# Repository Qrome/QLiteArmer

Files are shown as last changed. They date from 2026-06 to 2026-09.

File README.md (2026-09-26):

# QLiteArmer — HD Armer and Full OSD with Dual‑Core RP2040 Telemetry MSP DisplayPort Processor

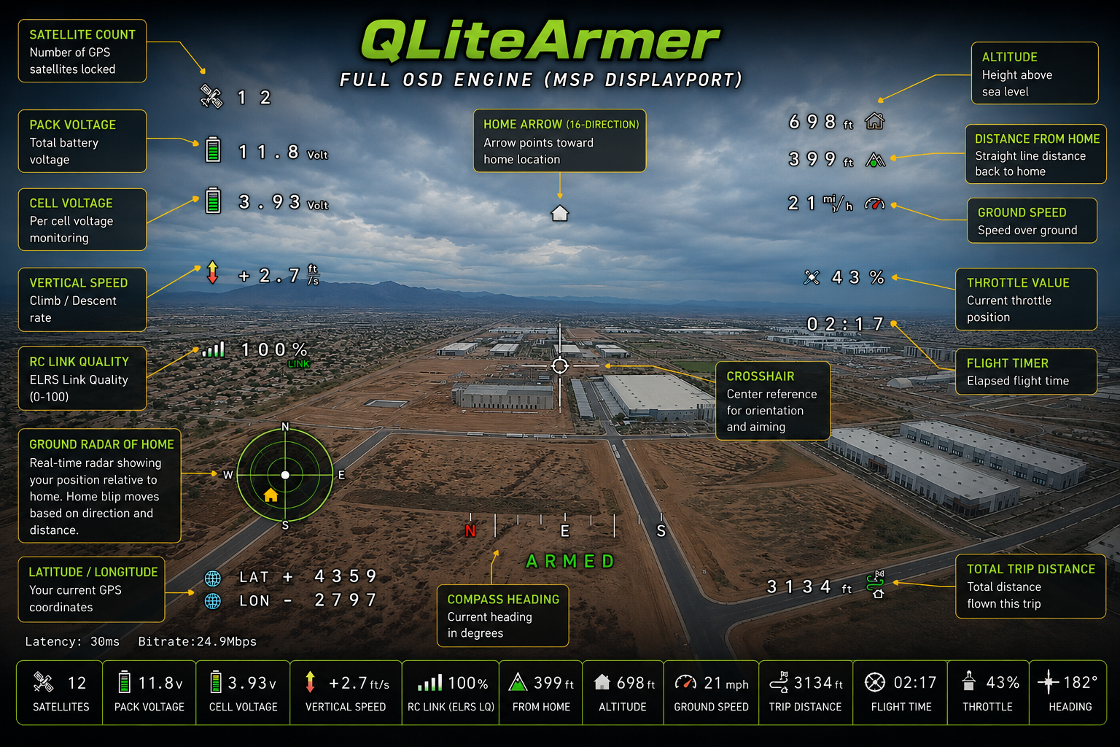
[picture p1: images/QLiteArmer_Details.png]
QLiteArmer Custom PCB — Fully Assembled


QLiteArmer is a dual‑core RP2040‑based telemetry OSD and HD arming system designed for FPV pilots, RC FPV vehicles, RC builders, and embedded developers.  
It provides:

- Full Betaflight‑style OSD for DJI O3/O4 and Walksnail Avatar HD  
- GPS + barometer telemetry processing  
- CRSF/ELRS channel breakout  
- PWM‑based arming (Channel 5)  
- 8‑channel servo expansion  
- Deterministic, non‑blocking architecture  

QLiteArmer is an OSD and arming module — arming is **controlled by RC PWM Channel 5**.

**[Get the QLiteArmer PCB Short Kit Here](https://www.etsy.com/shop/BSRC?section_id=59459029)**

---

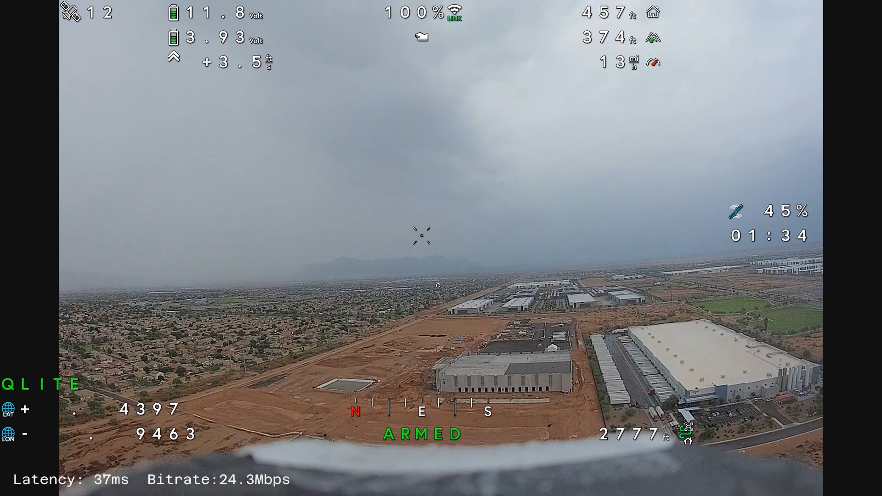
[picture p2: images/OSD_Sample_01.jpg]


## ✨ Features

### **Full OSD Engine (MSP DisplayPort)**
QLiteArmer includes a complete Betaflight‑compatible OSD renderer supporting:

- Satellite count  
- Pack voltage  
- Cell voltage  
- Vertical speed  
- RC link quality (ELRS LQ)  
- Distance from home  
- Altitude  
- Ground speed  
- Total trip distance  
- Latitude / longitude  
- Home arrow (16‑direction)  
- Ground radar of home  
- Crosshair  
- Flight timer  
- Throttle value  
- Compass heading

Compatible with:

- **DJI O3 / O4 Air Unit**
- **Walksnail Avatar HD (Goggles X / VTX)**

Uses Betaflight character mappings and custom glyphs for home arrow rendering.

---

## 🖼 Betaflight-Compatible Character Map (Walksnail Avatar HD)

This project includes a full custom character map matching Betaflight’s DisplayPort glyph layout, adapted for Walksnail Avatar HD.

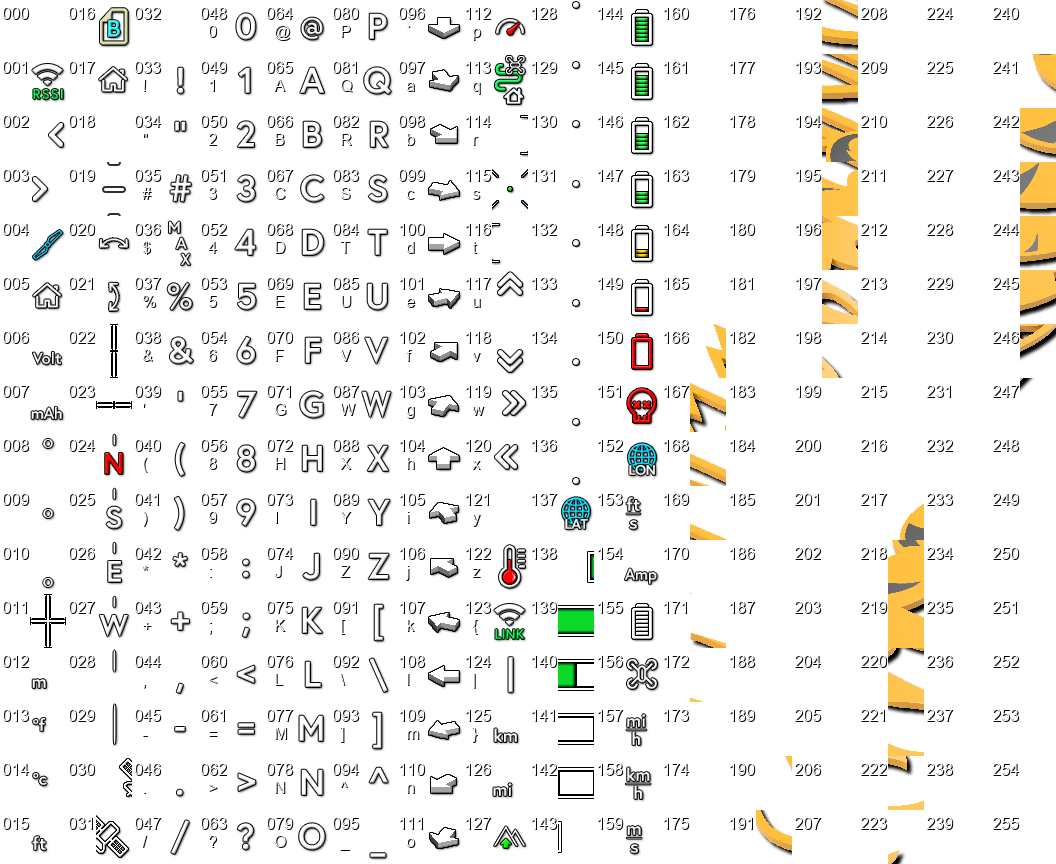
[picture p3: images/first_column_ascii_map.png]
Betaflight-Compatible Character Map (Walksnail Avatar HD)

---

## 🎮 PWM‑Based Arming (Channel 5)

Arming is now **100% PWM‑based**:

- Uses RC Channel 5 (default)
- Arms when PWM > threshold (default: 1700 µs)
- Disarms when PWM < threshold  

This ensures predictable, pilot‑controlled arming behavior.

---

## 🛰 Telemetry System

### **GPS Telemetry**
- Autodetects baud rate  (9600, 38400, 57600, 115200)
- Home position lock  
- Distance from home  
- Bearing to home  
- Ground radar showing home  
- Ground speed  
- Latitude / longitude  
- Total trip distance  
- GPS fix + satellite count  

### **Barometer (BMP280)**
- Altitude (cm)  
- Vertical speed (cm/s)  

### **Battery Monitoring**
- VBAT via ADC  
- Configurable voltage divider  
- Pack voltage displayed in OSD  
- Per cell voltage  

### **Units**
- Metric or Imperial (configurable)

---

## 🧩 Servo Expansion (8‑Channel PWM Output)

QLiteArmer includes a hardware‑accurate servo expander:

- 8 PWM outputs  
- Per‑channel min/max mapping  
- Per‑channel failsafe values  
- Frequency‑matched output  
- CRSF/ELRS channel passthrough  
- Ultra‑stable RP2040 hardware PWM  

Define individual channel range and failsafe in the config.h file:
```C
static const ChannelMap CH_MAP[8] = {
    {988, 2012, 1500},   // CH1
    {988, 2012, 1500},   // CH2
    {988, 2012, 1000},   // CH3 (Throttle failsafe = 1000)
    {988, 2012, 1500},   // CH4 
    {988, 2012, 1500},   // CH5
    {500, 2500, 1500},   // CH6 (expanded range)
    {988, 2012, 1500},   // CH7
    {988, 2012, 1500}    // CH8
};
```

---

## ⚠️ ESC Safety and Failsafe Configuration

**Always secure the plane on the bench and remove the propeller before powering the ESC for setup, calibration, firmware testing, or failsafe checks. Remove all propellers on multi-motor aircraft.**

Only **Channel 3** is configured with a **1000 µs throttle failsafe** by default. The other channels default to **1500 µs**, which can command a motor to run on an ESC that uses minimum throttle to stop.

**If you connect an ESC to any channel other than CH3, you must set that channel's `failsafeUs` in `QLiteArmer/config.h` to the correct motor-stopped value for your ESC before powering it.** Configure every ESC output individually, including a second ESC on CH6. QLiteArmer cannot automatically identify which outputs are connected to ESCs.

Each `CH_MAP` entry is `{minUs, maxUs, failsafeUs}`. The third value controls the output during PWM startup and when loss of valid ELRS channel data triggers failsafe. For example, for an ESC on CH6 that uses 1000 µs to stop, replace the CH6 entry with:

```C
    {988, 2012, 1000},   // CH6: ESC with 1000 µs stopped-throttle failsafe
```

Use the range and stopped-throttle value required by your ESC; a bidirectional ESC may require a neutral value instead. Save the configuration, rebuild, and upload the firmware after making changes.

With the propeller removed, verify that the motor remains stopped during startup, when QLiteArmer is restarted while the ESC stays powered, and when the radio link is lost. **Live throttle resumes automatically when valid ELRS channel data returns**, so a raised throttle stick can restart the motor. Channel 5's HD/VTX arming state does not gate the ESC PWM outputs; do not treat it as a motor safety lock.

---

## ⚙ Pin Map

| Function | Pin(s) | Notes |
| --- | --- | --- |
| **CRSF / ELRS UART** | GP8 (TX), GP9 (RX) | Primary RC link |
| **MSP UART (VTX)** | GP0 (TX), GP1 (RX) | DJI / Walksnail |
| **I²C (BMP280)** | GP4 (SDA), GP5 (SCL) | Barometer |
| **VBAT ADC** | GP26 | Voltage divider |
| **PWM CH1–CH8** | 13, 12, 11, 10, 7, 6, 3, 2 | Servo/motor outputs |
| **RGB LED** | GP16 | Onboard WS2812 |
| **GPS** | GP14 (TX), GP15 (RX) | 4‑wire GPS |

---
## Software & Environment Setup

This project is built for the Raspberry Pi Pico / RP2040 / RP2350 architecture using the Arduino IDE. Follow the steps below to configure your development environment.

### 1. Install the Board Support Package (BSP)
You must use the Arduino Pico core maintained by Earle F. Philhower, III. 

1. Open the Arduino IDE.
2. Navigate to **File** -> **Preferences**.
3. Locate the **Additional Boards Manager URLs** field and paste the following URL:
   ```
   https://github.com/earlephilhower/arduino-pico/releases/download/global/package_rp2040_index.json
   ```
4. Click **OK**.
5. Go to **Tools** -> **Board** -> **Boards Manager...**
6. Search for `Pico` or `Philhower` and install **Raspberry Pi Pico/RP2040/RP2350** by *Earle F. Philhower, III*.
7. Once installed, go to **Tools** -> **Board** -> **Raspberry Pi Pico/RP2040** and select **Waveshare RP2040 Zero**.

### 2. Install Required Libraries
Open the Arduino Library Manager (**Tools** -> **Manage Libraries...** or press `Ctrl+Shift+I` / `Cmd+Shift+I`) to search for and install:

* **Adafruit BMP280 Library** (by Adafruit)
* **NeoPixelBus** (by Makuna)

> 💡 **Note:** When installing the `Adafruit BMP280` library, the IDE will ask to install required dependencies (like `Adafruit BusIO` and `Adafruit Unified Sensor`). Make sure to select **Install All** so everything compiles successfully.
---

## 🛠 Hardware Overview

### **QLiteArmer Custom PCB**
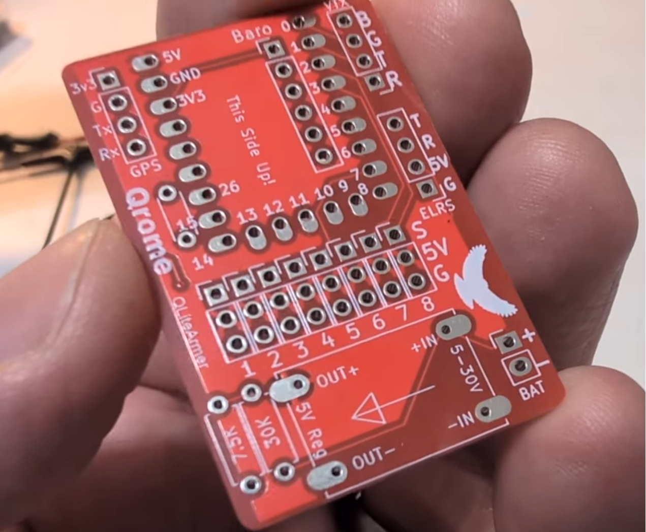
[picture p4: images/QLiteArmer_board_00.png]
QLiteArmer Custom PCB — Bare Board


### **QLiteArmer Custom PCB — Fully Assembled**
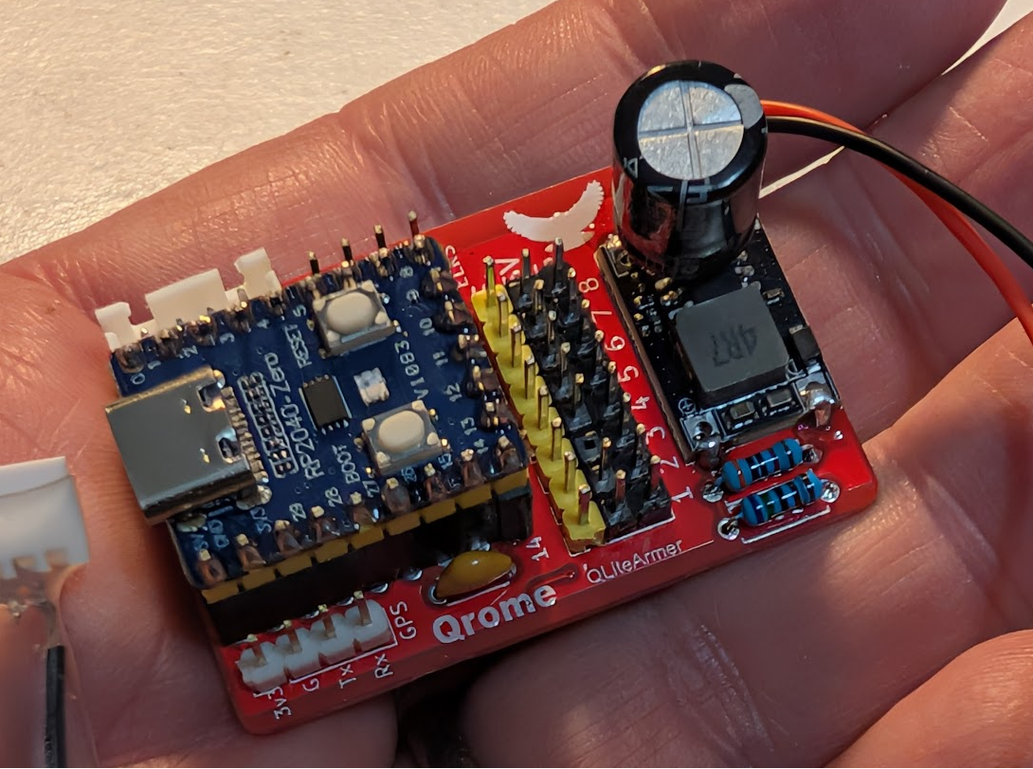
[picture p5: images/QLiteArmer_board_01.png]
QLiteArmer Custom PCB — Fully Assembled


## 🧰 Parts List (with Affiliate Links)

These are the recommended components for building a complete QLiteArmer module.  
All links are affiliate links that help support the project at no additional cost.

### **Core Components**
- **QLiteAmer PCB Board by Qrome**  
  https://www.etsy.com/shop/BSRC?section_id=59459029

- **RP2040‑Zero**  
  https://amzn.to/4v0oCKq

- **M100-5883 GPS (115200 bps 5Hz - 10Hz)**  
  https://amzn.to/4weRRKt

- **HGLRC ExpressLRS 915 MHz Receiver**  
  https://amzn.to/4w56T5E

- **BMP280‑3.3 Atmospheric Pressure Sensor**  
  https://amzn.to/44y8Onq

### **Power & Regulation**
- **3A Mini DC‑DC Buck Converter (5.5–30 V → 5 V)**  
  https://amzn.to/4wcNi3h

### **Passive Components**
- **30 kΩ Resistor (¼ W)**  
  https://amzn.to/3StSnWB

- **7.5 kΩ Resistor (¼ W)**  
  https://amzn.to/440p8Nx

- **0.1 µF (100 nF) Ceramic Capacitors (104)**  
  https://amzn.to/4xO8TAQ

- **1000 µF 25 V Electrolytic Capacitor (optional)**  
  https://amzn.to/4vtyai8

### **Headers & Connectors**
- **Pin Header, 2.54mm 40Pin Male and Female Header Pins**  
  https://amzn.to/4oQfh6B

### **Other Recommended Items**
- **RADIOMASTER TX15 Max**  
  https://amzn.to/4vCAtQa

- **Walksnail Avatar HD FPV Goggles X**  
  https://amzn.to/4f2cXWN

- **Walksnail Avatar GT2 Kit – Air Unit**  
  https://amzn.to/4geaycN  

QLiteArmer OSD and HD Armer Detailed Build - RP2040 Zero FPV System (https://www.youtube.com/watch?v=8tNotUI8HCQ)

---

## 🚀 How It Works (High‑Level)

1. **Boot**
   - System initializes dual‑core architecture  
   - Blue LED indicates boot state  

2. **Telemetry Acquisition**
   - Core 1 handles GPS, barometer, battery, and OSD  
   - Core 0 handles CRSF/ELRS and PWM output  

3. **OSD Rendering**
   - MSP DisplayPort frames generated in real time  
   - Betaflight‑compatible glyphs  
   - Home arrow computed from GPS bearing  

4. **Arming**
   - PWM Channel 5 controls arming  
   - Red LED is holding and ready to arm  
   - Green LED is armed with high power and recording  
   - Amber LED no VTX detected

5. **Servo Expansion**
   - CRSF channels mapped to PWM outputs  
   - Failsafe values applied on link loss  

---

## 🧠 System Architecture (Technical)

### **Core 0 (Time‑Critical)**
- CRSF/ELRS UART  
- PWM output generation  
- MSP heartbeat  
- Channel mapping  
- Failsafe handling  

### **Core 1 (Telemetry + OSD)**
- MSP DisplayPort  
- GPS parsing  
- Barometer updates  
- Battery ADC  
- OSD composition  
- State machine  
- LED driver  

### **SerialPIO Notes**
- SerialPIO is used for GPS  
- Requires careful initialization order  
- LED initialization must occur before SerialPIO  

### **RP2040 vs RP2350**
- Both fully supported  
- LED color order differs between boards (Red and Green are swapted)  
- Auto‑detected via compile‑time selection  

---

## 🔧 Configuration Reference

### **PWM Channel Mapping**
Each channel has:
- `minUs`
- `maxUs`
- `failsafeUs`

Example (from config.h):
```C
static const ChannelMap CH_MAP[8] = {
    {988, 2012, 1500},   // CH1
    {988, 2012, 1500},   // CH2
    {988, 2012, 1000},   // CH3 (Throttle failsafe = 1000)
    {988, 2012, 1500},   // CH4 
    {988, 2012, 1500},   // CH5
    {500, 2500, 1500},   // CH6 (expanded range)
    {988, 2012, 1500},   // CH7
    {988, 2012, 1500}    // CH8
};
```

### **Arming Settings**
- `PWM_ARM_CHANNEL = 4` (Channel 5 -- ZERO based mapping)  
- `PWM_ARM_THRESHOLD = 1700`  
- `PWM_NO_SIGNAL_US = 900`  

### **Battery Divider**
Default:
- R1 = 30k  
- R2 = 7.5k  

### **Telemetry Rates**
- Battery: 5 Hz  
- Altitude: 5 Hz  

### **Units**
- Metric or Imperial  

### **Timing**
- VTX detection timeout: 5 minutes  
- Heartbeat: 200 ms  

### **LED**
- LED pin: GP16  
- LED count: 1  
- RP2040/RP2350 color order handled internally  

### **Home Arrow Glyph Table**
Rows 96–111  
16 directions  
22.5° increments  
CCW orientation  

---

## 🧪 Tested Hardware

- RP2040‑Zero  
- RP2350-Zero  
- DJI O3 / O4 Air Unit  
- Walksnail Avatar HD  
- ELRS receivers  
- BMP280 barometer  
- Standard GPS modules  

---

## 📄 License

MIT License — free to modify, extend, and integrate.

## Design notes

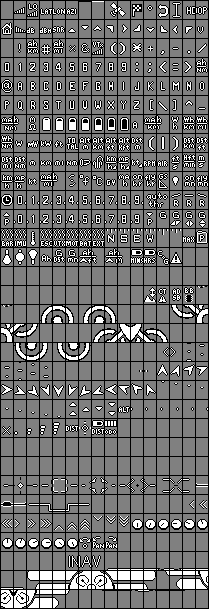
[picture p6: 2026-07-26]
images/DJI-Font.png

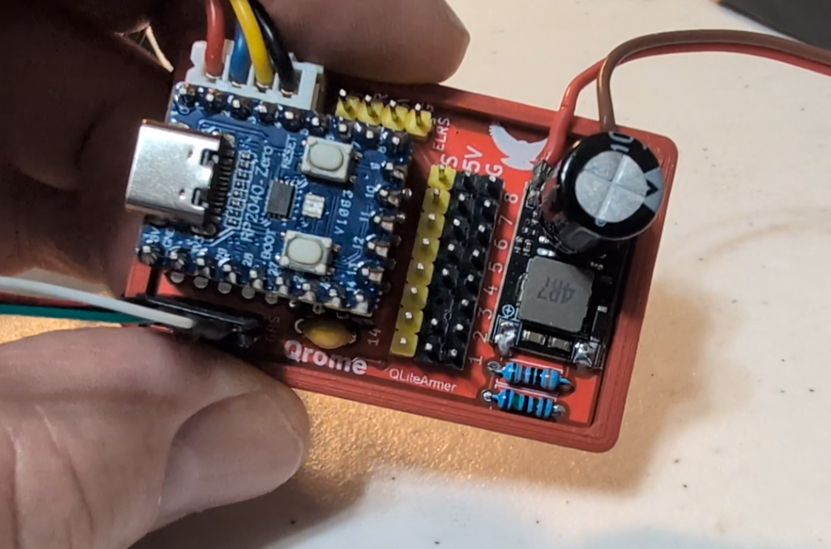
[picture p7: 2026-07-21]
images/QLiteArmer_box.png

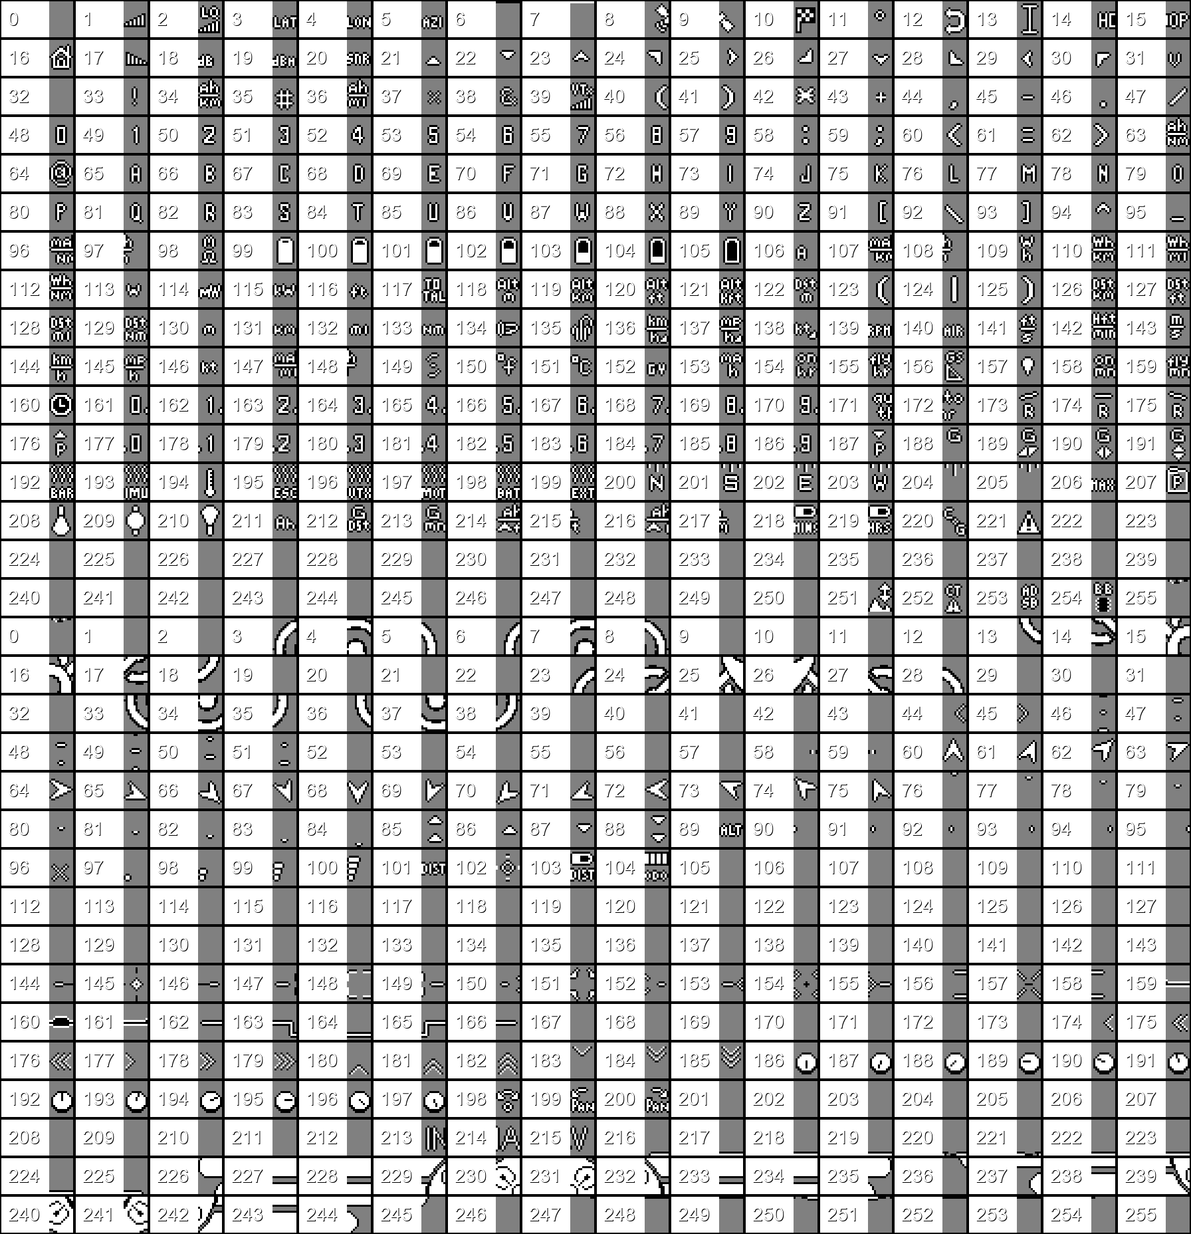
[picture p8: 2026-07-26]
images/dji_fontmap.png

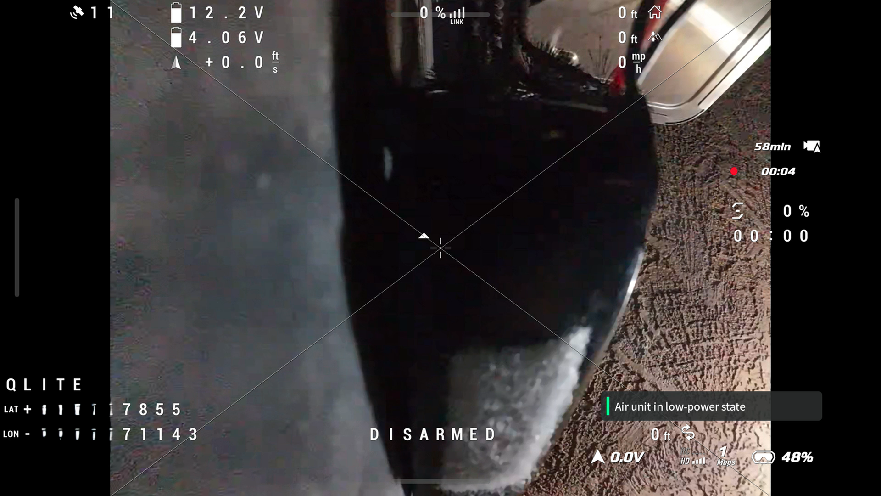
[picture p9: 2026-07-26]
images/DJI_OSD_Sample_v1.01.png

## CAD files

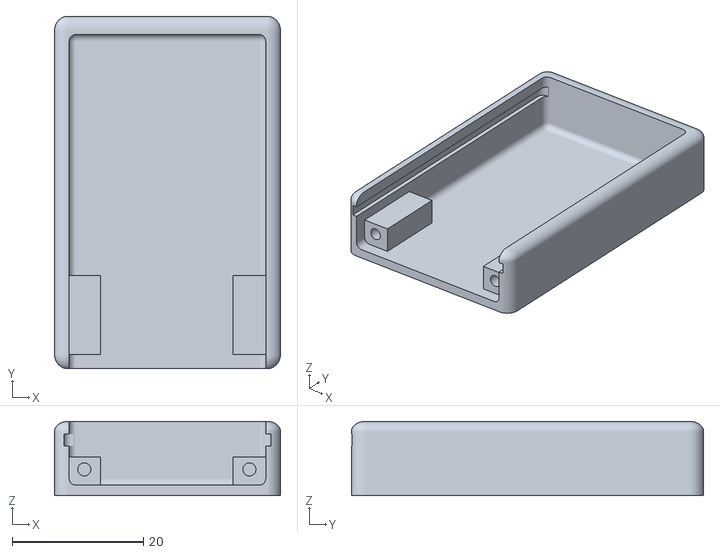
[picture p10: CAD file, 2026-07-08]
STL_files/QliteArmer Box.stl
34.5 x 53.8 x 11.3

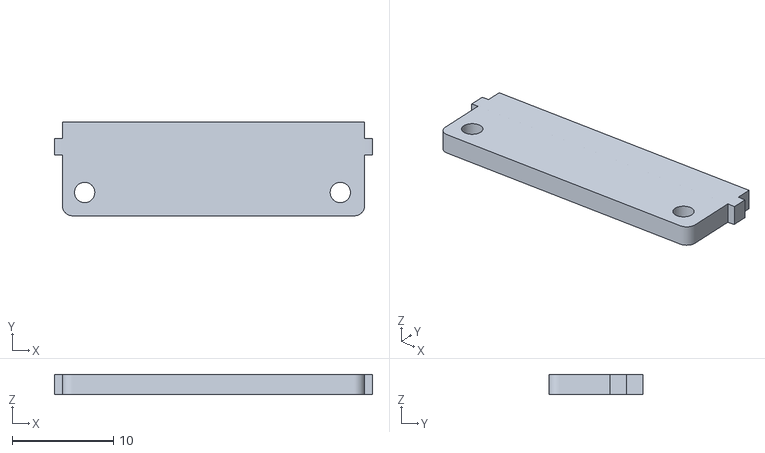
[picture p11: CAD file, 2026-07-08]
STL_files/QliteArmer Box end cap.stl
31.3 x 9.23 x 2.00

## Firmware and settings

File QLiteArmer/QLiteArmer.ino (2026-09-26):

/*
  HD_Amer — Auto‑Arming MSP Transmitter Firmware
  by David Payne (Qromer)
  Target MCU: Waveshare RP2040‑Zero
*/

#include <Arduino.h>
#include "SharedTelemetry.h"
#include "Telemetry.h"
#include "config.h"
#include "led.h"
#include "state_machine.h"
#include "detection.h"
#include "bf_msp.h"
#include "CrossfireELRS.h"
#include "PWMDriver.h"
#include <SerialPIO.h>
#include "GPS.h"

float distFiltM = 0.0f;
bool distFiltInit = false;
CrossfireELRS crsf;
PWMDriver pwm;
Telemetry telemetry;
SerialPIO SerialGPS(PIN_GPS_TX, PIN_GPS_RX); 
GPS gps;

// Shared across cores — volatile for safety
volatile bool systemReady = false;
volatile bool loopReady = false;
volatile bool gpsReady = false;

inline void debugPrint(const String &msg) {
    if (Serial) {
        Serial.println(msg);
    }
}

void populateSharedTelemetry() {
    gps.update();

    // --- GPS distance smoothing ---
    float rawDist = gps.getDistanceFromHomeM();

    if (!distFiltInit) {
        distFiltM = rawDist;
        distFiltInit = true;
    } else {
        distFiltM = distFiltM * 0.8f + rawDist * 0.2f;
    }

    // Push into shared telemetry
    sharedTelem.gpsDistHomeM = distFiltM;
    sharedTelem.gpsFix = gps.hasFix();
    sharedTelem.gpsSats = gps.getSatCount();
    sharedTelem.gpsGroundSpeedCms = gps.getGroundSpeed();
    sharedTelem.gpsCourseDeg = gps.getCourse() * 0.1f;          // FIXED: real degrees
    sharedTelem.gpsBearingToHomeDeg = gps.getBearingToHomeDeg();
    sharedTelem.gpsLatDeg = gps.getLatitude() * 1e-7f;
    sharedTelem.gpsLonDeg = gps.getLongitude() * 1e-7f;

    sharedTelem.baroAltCm = telemetry.readAltitudeCm();
    sharedTelem.baroVSpeedCms = telemetry.readVSpeedCms();
    sharedTelem.batteryMv = telemetry.readBatteryMv();

    // -------------------------------------------------------
    // Unified Home-Direction Pipeline (arrow + radar)
    // -------------------------------------------------------

    float bearingToHome = sharedTelem.gpsBearingToHomeDeg;   // Earth-frame
    float headingDeg    = sharedTelem.gpsCourseDeg;          // Earth-frame (C.O.G.)
    float distFt        = sharedTelem.gpsDistHomeM * 3.28084f;

    // 1. Pilot-relative bearing
    float rel = bearingToHome - headingDeg;
    if (rel < 0) rel += 360.0f;
    if (rel >= 360.0f) rel -= 360.0f;

    // 2. Smooth the relative bearing
    static float relSmooth = 0.0f;
    relSmooth = relSmooth * 0.90f + rel * 0.10f;

    // 3. Radar radius (RADAR_CELL_FEET ft per cell, max RADAR_CELL_RADIUS cells) see config.h
    float rawRadius = distFt / RADAR_CELL_FEET;
    if (rawRadius > RADAR_CELL_RADIUS) rawRadius = RADAR_CELL_RADIUS;

    static float radiusSmooth = 0.0f;
    radiusSmooth = radiusSmooth * 0.85f + rawRadius * 0.15f;

    // 4. Convert raw relative bearing to radians
    float theta = radians(rel); 

    // 5. Radar offsets around crosshair (9, 25)
    // Calculate the raw mathematical target grid offsets
    float targetRowOffset = -cos(theta) * rawRadius;
    float targetColOffset =  sin(theta) * rawRadius;

    // 6. Responsive Tuning: Use a light filter (0.40f) instead of 0.85f
    // This removes jerky jumps but updates within 2-3 frames
    static float rowOffsetSmooth = 0.0f;
    static float colOffsetSmooth = 0.0f;
    rowOffsetSmooth = rowOffsetSmooth * 0.60f + targetRowOffset * 0.40f;
    colOffsetSmooth = colOffsetSmooth * 0.60f + targetColOffset * 0.40f;

    // Convert directly to final grid coordinates
    int newRow = RADAR_ROW_CENTER + (int)round(rowOffsetSmooth);
    int newCol = RADAR_COL_CENTER + (int)round(colOffsetSmooth);

    newRow = constrain(newRow, RADAR_ROW_CENTER - RADAR_CELL_RADIUS, RADAR_ROW_CENTER + RADAR_CELL_RADIUS);
    newCol = constrain(newCol, RADAR_COL_CENTER - RADAR_CELL_RADIUS, RADAR_COL_CENTER + RADAR_CELL_RADIUS);

    // 7. Store unified values in SharedTelemetry
    sharedTelem.homeRelativeDeg       = rel;
    sharedTelem.homeRelativeSmoothDeg = relSmooth;
    sharedTelem.homeDistanceFt        = distFt;
    sharedTelem.homeRadarRadius       = radiusSmooth;
    sharedTelem.homeRadarRow          = newRow;
    sharedTelem.homeRadarCol          = newCol;
}

// -------------------------------------------------------
// Core 0 — RC input + PWM output (time-critical)
// -------------------------------------------------------
void setup() {
    // Establish configured failsafe pulses before USB or peripheral waits.
    pwm.begin(PWM_PINS, 8);
    Serial.begin(115200);
    unsigned long start = millis();
    while (!Serial && (millis() - start < 1500)) {
        delay(10);
    }

    debugPrint("Starting up QLiteArmer...");

    // CRSF receiver
    crsf.begin(PIN_CRSF_RX, PIN_CRSF_TX);

    systemReady = true;
    debugPrint("Core 0 ready.");
}

void loop() {
    // RC input and failsafe output must run during core 1 initialization.
    // CRSF receiver — time sensitive, must run every loop
    crsf.update();

    // PWM outputs from CRSF channels
    for (int i = 0; i < 8; i++) {
        pwm.writeFromCRSF(i, crsf.getChannel(i), crsf.crsfLinkActive);
    }

    // MSP still waits for its existing core 1 initialization sequence.
    if (!loopReady) return;

    bf_msp_parse_incoming();       // always — reads and responds to polls
    bf_msp_firstbeat_update();     // always — no-op after firstbeat completes
    bf_msp_heartbeat_update((currentState == STATE_ARMED)); // always — skips DP heartbeat for V1
    bf_msp_dp_update_osd_nb();     // always — no-op for V1, active for O3/Avatar

    // Add to loop() temporarily for diagnosis
    static uint32_t lastDebugMs = 0;
    if (millis() - lastDebugMs > 2000) {
        lastDebugMs = millis();
        VtxSystemType t = bf_msp_get_vtx_type();
        Serial.print("[DEBUG] VTX type detected: ");
        switch(t) {
            case VTX_UNKNOWN:   Serial.println("UNKNOWN"); break;
            case VTX_DJI_V1:    Serial.println("DJI V1");  break;
            case VTX_DJI_O3:    Serial.println("DJI O3/O4"); break;
            case VTX_WALKSNAIL: Serial.println("Walksnail Avatar"); break;
        }
    }
}

// -------------------------------------------------------
// Core 1 — MSP arming + telemetry (background)
// -------------------------------------------------------
void setup1() {
    // Wait for Core 0 to finish its setup
    while (!systemReady) {
        delay(100);
    }

    // MSP UART to VTX
    Serial1.setTX(0);
    Serial1.setRX(1);
    Serial1.begin(MSP_BAUD);

    // Telemetry (BMP280 + ADC)
    telemetry.begin();

    // MSP subsystem
    bf_msp_init(Serial1, telemetry, crsf);

    delay(200);
    // LED
    ledInit();

    delay(200);

    // GPS on SerialPIO using pins 14 (TX) and 15 (RX)
    static const uint32_t gpsBauds[] = {9600, 38400, 57600, 115200};
    gps.begin(SerialGPS);

    Serial.println("[GPS] Starting autodetect...");
    bool gpsOK = gps.autodetectBaud(gpsBauds, 4, 900);

    if (gpsOK) {
        Serial.println("[GPS] Autodetect successful.");
    } else {
        Serial.println("[GPS] WARNING: No GPS detected.");
    }

    // Start state machine
    enterState(STATE_BOOT_DETECT);

    // VTX detection parser
    detectionInit();

    debugPrint("Core 1 ready.");
    loopReady = true;
}

static uint32_t lastGpsPrint = 0;

void loop1() {
    while (!loopReady) {
        delay(10);
    }
    static SystemState lastState = STATE_BOOT_DETECT;
    telemetry.update();  
    
    populateSharedTelemetry();

    // Start tracking only when GPS fix + 6 sats and armed
    if (!gpsReady && sharedTelem.gpsFix && sharedTelem.gpsSats >= 6) {
        gpsReady = true;
    }


    uint32_t now = millis();

    // Print GPS debug once per second
    if (now - lastGpsPrint > 2000) {
        lastGpsPrint = now;

        Serial.print("[GPS] Fix=");
        Serial.print(gps.hasFix());
        Serial.print(" Sats=");
        Serial.print(gps.getSatCount());
        Serial.print(" Lat=");
        Serial.print(gps.getLatitude());
        Serial.print(" Lon=");
        Serial.print(gps.getLongitude());
        Serial.print(" Alt(cm)=");
        Serial.print(gps.getAltitudeMSL());
        Serial.print(" GS(cm/s)=");
        Serial.print(gps.getGroundSpeed());
        Serial.print(" Course=");
        Serial.println(gps.getCourse());
    }

    uint16_t armRaw = crsf.getChannel(PWM_ARM_CHANNEL);
    stateMachineUpdate(armRaw, crsf.crsfLinkActive);
    // --- Detect ARM transition using state machine ---
    if (currentState == STATE_ARMED && lastState != STATE_ARMED && gpsReady) {
        // Rising edge: system just became ARMED
        gps.forceSetHome();
        telemetry.resetBaseAltitude();
        sharedTelem.gpsTotalDistM = 0.0f;
        sharedTelem.gpsTotalActive = false;
        sharedTelem.gpsPrevValid = false;
    }

    // Only track when ARMED + GPS locked
    if (currentState == STATE_ARMED && gpsReady) {

        if (!sharedTelem.gpsTotalActive) {
            // First valid point after arming
            sharedTelem.gpsPrevLatDeg = sharedTelem.gpsLatDeg;
            sharedTelem.gpsPrevLonDeg = sharedTelem.gpsLonDeg;
            sharedTelem.gpsPrevValid = true;
            sharedTelem.gpsTotalActive = true;
        }

        if (sharedTelem.gpsPrevValid) {
            // Haversine incremental distance
            float lat1 = radians(sharedTelem.gpsPrevLatDeg);
            float lon1 = radians(sharedTelem.gpsPrevLonDeg);
            float lat2 = radians(sharedTelem.gpsLatDeg);
            float lon2 = radians(sharedTelem.gpsLonDeg);

            float dLat = lat2 - lat1;
            float dLon = lon2 - lon1;

            float a = sin(dLat/2)*sin(dLat/2) +
                    cos(lat1)*cos(lat2)*sin(dLon/2)*sin(dLon/2);

            float c = 2 * atan2(sqrt(a), sqrt(1-a));

            const float R = 6371000.0f; // meters
            float deltaM = R * c;

            // Reject GPS jumps > 100m
            float maxJump = sharedTelem.gpsGroundSpeedCms * 0.05f; // 50ms window
            if (deltaM < maxJump)
                sharedTelem.gpsTotalDistM += deltaM;
        }

        // Update previous
        sharedTelem.gpsPrevLatDeg = sharedTelem.gpsLatDeg;
        sharedTelem.gpsPrevLonDeg = sharedTelem.gpsLonDeg;
        sharedTelem.gpsPrevValid = true;

    } else {
        // Not tracking
        sharedTelem.gpsPrevValid = false;
    }

    lastState = currentState;
}

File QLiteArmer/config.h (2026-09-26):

#pragma once
#include <Arduino.h>

#define VERSION "1.04"


#define SHOW_THROTTLE_PERCENT true
#define SHOW_GROUND_RADAR true
#define SHOW_COMPASS_HEADING true
#define SHOW_VERTICLE_SPEED true
#define SHOW_CROSSHAIR true


// Units for altitude + vertical speed
#define OSD_UNITS_METRIC     0
#define OSD_UNITS_IMPERIAL   1

// Set your preferred default here:
#define OSD_UNITS OSD_UNITS_IMPERIAL   // use OSD_UNITS_IMPERIAL or OSD_UNITS_METRIC

// ======================================================
// Per‑Channel PWM Mapping (microseconds)
// ======================================================
struct ChannelMap {
    uint16_t minUs;       // mapped minimum
    uint16_t maxUs;       // mapped maximum
    uint16_t failsafeUs;  // output when CRSF link is lost
};


static const ChannelMap CH_MAP[8] = {
    {988, 2012, 1500},   // CH1
    {988, 2012, 1500},   // CH2
    {988, 2012, 1000},   // CH3 (Throttle failsafe = 1000)
    {988, 2012, 1500},   // CH4 
    {988, 2012, 1500},   // CH5
    {988, 2012, 1500},   // CH6     {500, 2500, 1500},  //CH6 (expanded range)(expanded range)
    {988, 2012, 1500},   // CH7
    {988, 2012, 1500}    // CH8
};

static const uint8_t throttleIndex = 2; //0 based index so 2 = CH3
static const char* CraftName = "QLITE";  // Use uppercase and numbers

// ======================================================
// Pin Configuration
// ======================================================
#define PIN_CRSF_RX     9
#define PIN_CRSF_TX     8

#define PIN_GPS_TX      14
#define PIN_GPS_RX      15

#define PIN_I2C_SDA     4
#define PIN_I2C_SCL     5

#define PIN_VBAT_ADC    26   // ADC0

// ======================================================
// PWM Output Pins (8 channels)
// ======================================================
static const uint8_t PWM_PINS[8] = {
    13, 12, 11, 10, 7, 6, 3, 2
};

// ======================================================
// Battery Divider (30k / 7.5k)
// ======================================================
#define VBAT_R1 30000.0f
#define VBAT_R2  7500.0f

// Ground Radar Options
static const uint16_t RADAR_CELL_FEET    = 300;    // number of feet per cell
static const float RADAR_CELL_RADIUS     = 4.0F;   // number of cells radius around center
static const int RADAR_ROW_CENTER        = 9;      // row center 1080p is 9
static const int RADAR_COL_CENTER        = 25;     // column center 1080p is 25

// PWM-based arming (optional)
static const uint8_t PWM_ARM_CHANNEL     = 4;     // 0 based array 0 - 7
static const uint16_t PWM_ARM_THRESHOLD  = 1700;  // µs required to arm
static const uint16_t PWM_DISARM_THRESHOLD = 1600;  // must drop below this (not 1700) to disarm
static const uint32_t ARM_DEBOUNCE_MS      = 150;    // must hold past threshold this long
static const uint16_t PWM_NO_SIGNAL_US   = 900;   // below this = no PWM present

// UART
static const uint32_t MSP_BAUD = 115200;

// Timings (ms)
static const uint32_t VTX_DETECTION_TIMEOUT_MS = 300000;  // 5 minutes
static const uint32_t HEARTBEAT_INTERVAL_MS    = 200;    // BTFL use 150 (~6.7 Hz)

// Error thresholds
static const uint8_t BAD_CHECKSUM_THRESHOLD   = 3;

// LED
static const uint8_t LED_PIN   = 16;   // RP2040-Zero onboard WS2812
static const uint8_t LED_COUNT = 1;

// 16‑direction home arrow glyphs (rows 96–111), CCW, 22.5° per step
static const uint8_t arrowRows[16] = {
    96,  //   0° DOWN
    111, //  22.5° DOWN‑SLIGHT‑LEFT
    110, //  45° DOWN‑LEFT
    109, //  67.5° LEFT‑DOWN
    108, //  90° LEFT
    107, // 112.5° LEFT‑SLIGHT‑UP
    106, // 135° LEFT‑UP
    105, // 157.5° UP‑LEFT
    104, // 180° UP
    103, // 202.5° UP‑SLIGHT‑RIGHT
    102, // 225° UP‑RIGHT
    101, // 247.5° RIGHT‑UP
    100, // 270° RIGHT
    99,  // 292.5° RIGHT‑SLIGHT‑DOWN
    98,  // 315° RIGHT‑DOWN
    97   // 337.5° DOWN‑SLIGHT‑RIGHT
};

static const uint8_t arrowRowsDJI[16] = {
    68,  //   0° DOWN
    69, //  22.5° DOWN‑SLIGHT‑LEFT
    70, //  45° DOWN‑LEFT
    71, //  67.5° LEFT‑DOWN
    72, //  90° LEFT
    73, // 112.5° LEFT‑SLIGHT‑UP
    74, // 135° LEFT‑UP
    75, // 157.5° UP‑LEFT
    60, // 180° UP
    61, // 202.5° UP‑SLIGHT‑RIGHT
    62, // 225° UP‑RIGHT
    63, // 247.5° RIGHT‑UP
    64, // 270° RIGHT
    65,  // 292.5° RIGHT‑SLIGHT‑DOWN
    66,  // 315° RIGHT‑DOWN
    67   // 337.5° DOWN‑SLIGHT‑RIGHT
};

// 24 slots base + 12 slot overflow = 36 items total.
// Spacing: 15 degrees per index. 3 small ticks (28) between each cardinal.
static const uint8_t compassList[36] = {
    24, 28, 29, 28, 26, 28, 29, 28, // N to E
    25, 28, 29, 28, 27, 28, 29, 28, // S to W
    24, 28, 29, 28, 26, 28, 29, 28, // N to E (Wrap loop starts)
    25, 28, 29, 28, 27, 28, 29, 28  // S to W
};

static const uint8_t compassListDJI[36] = {
    200, 205, 204, 205, 202, 205, 204, 205, // N to E
    201, 205, 204, 205, 203, 205, 204, 205, // S to W
    200, 205, 204, 205, 202, 205, 204, 205, // N to E (Wrap loop starts)
    201, 205, 204, 205, 203, 205, 204, 205  // S to W
};

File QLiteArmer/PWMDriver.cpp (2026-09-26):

#include "PWMDriver.h"
#include "hardware/pwm.h"
#include "hardware/clocks.h"

void PWMDriver::begin(const uint8_t* pins, uint8_t count) {
    outputCount = pins ? (count > 8 ? 8 : count) : 0;
    uint32_t sliceMask = 0;

    // Paired GPIOs share a slice. Stop all owned slices before configuring
    // either output, and keep the pins low until safe compare values exist.
    for (uint8_t i = 0; i < outputCount; ++i) {
        outputPins[i] = pins[i];
        uint slice = pwm_gpio_to_slice_num(pins[i]);
        pwm_set_enabled(slice, false);
        sliceMask |= 1u << slice;
        gpio_init(pins[i]);
        gpio_put(pins[i], false);
        gpio_set_dir(pins[i], GPIO_OUT);
    }

    pwm_config cfg = pwm_get_default_config();
    // 1 MHz counter: one count per microsecond, 20000 counts per frame.
    pwm_config_set_clkdiv(&cfg, (float)clock_get_hz(clk_sys) / 1000000.0f);
    pwm_config_set_wrap(&cfg, 19999);
    for (uint slice = 0; slice < 8; ++slice) {
        if (sliceMask & (1u << slice)) pwm_init(slice, &cfg, false);
    }

    for (uint8_t i = 0; i < outputCount; ++i) {
        smoothedUs[i] = CH_MAP[i].failsafeUs;
        pwm_set_gpio_level(outputPins[i], CH_MAP[i].failsafeUs);
    }
    for (uint8_t i = 0; i < outputCount; ++i) {
        gpio_set_function(outputPins[i], GPIO_FUNC_PWM);
    }
    for (uint slice = 0; slice < 8; ++slice) {
        if (sliceMask & (1u << slice)) pwm_set_enabled(slice, true);
    }
}

uint16_t PWMDriver::crsfToUs(uint8_t ch, uint16_t raw) {
    const uint16_t inMin = 172;
    const uint16_t inMax = 1811;
    if (raw < inMin) raw = inMin;
    if (raw > inMax) raw = inMax;
    int32_t span = (int32_t)CH_MAP[ch].maxUs - CH_MAP[ch].minUs;
    return (uint16_t)(CH_MAP[ch].minUs +
        (int32_t)(raw - inMin) * span / (inMax - inMin));
}

uint16_t PWMDriver::applySmoothing(uint8_t ch, uint16_t targetUs) {
    const float alpha = 0.25f;
    smoothedUs[ch] += alpha * (targetUs - smoothedUs[ch]);
    return (uint16_t)smoothedUs[ch];
}

void PWMDriver::writeUs(uint8_t ch, uint16_t us) {
    if (ch >= outputCount) return;
    pwm_set_gpio_level(outputPins[ch], us);
}

void PWMDriver::writeFromCRSF(uint8_t ch, uint16_t raw, bool activeLink) {
    if (ch >= outputCount) return;
    uint16_t us;
    if (!activeLink) {
        us = CH_MAP[ch].failsafeUs;
        // Prevent the pre-failsafe throttle value returning on reconnection.
        smoothedUs[ch] = us;
    } else {
        us = applySmoothing(ch, crsfToUs(ch, raw));
    }
    writeUs(ch, us);
}

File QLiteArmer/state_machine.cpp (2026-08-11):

#include "SerialPIO.h"
#include "config.h"
#include "led.h"
#include "state_machine.h"
#include "detection.h"
#include "bf_msp.h"

SystemState currentState = STATE_BOOT_DETECT;

static uint32_t stateStart    = 0;
static uint32_t lastHeartbeat = 0;

// ---------------------------------------------------------
void enterState(SystemState s) {
    currentState = s;
    stateStart   = millis();

    Serial.print("State Changed to: ");
    Serial.println(currentState);
    switch (s) {
        case STATE_BOOT_DETECT:   ledBlue();  break;
        case STATE_PRE_ARM_DELAY: ledRed();   break;
        case STATE_ARMED:         ledGreen(); break;
        case STATE_ERROR:         ledOff();   break;
    }
}

// ---------------------------------------------------------
// armValue   — CRSF raw (172–1811) or 0 if no signal
// linkActive — true when CRSF frames are arriving
// ---------------------------------------------------------
void stateMachineUpdate(uint16_t armValue, bool linkActive) {
    uint32_t now = millis();
    static uint32_t armCandidateStart   = 0;
    static uint32_t disarmCandidateStart = 0;
    
    // Convert CRSF raw to microseconds for threshold comparison
    // CRSF 172 = 988µs, CRSF 1811 = 2012µs  (linear)
    uint16_t armUs = 0;
    if (linkActive) {
        armUs = 988 + (uint32_t)(armValue - 172) * (2012 - 988) / (1811 - 172);
    }

    // Determine if a valid PWM signal is present
    bool pwmSignalPresent = linkActive && (armUs > PWM_NO_SIGNAL_US);

    switch (currentState) {

        // -------------------------------------------------
        case STATE_BOOT_DETECT:
            detectionPoll();

            if (vtxDetected) {
                bf_msp_firstbeat_start();
                enterState(STATE_PRE_ARM_DELAY);
            } else if (now - stateStart > VTX_DETECTION_TIMEOUT_MS) {
                enterState(STATE_ERROR);
            }
            break;

        // -------------------------------------------------
        case STATE_PRE_ARM_DELAY: {

            // Send disarmed heartbeat while waiting
            if (now - lastHeartbeat > HEARTBEAT_INTERVAL_MS) {
                lastHeartbeat = now;
                bf_msp_heartbeat_update(false);
            }

            if (pwmSignalPresent) {
                if (armUs >= PWM_ARM_THRESHOLD) {
                    if (armCandidateStart == 0) armCandidateStart = now;
                    if (now - armCandidateStart >= ARM_DEBOUNCE_MS) {
                        enterState(STATE_ARMED);
                        armCandidateStart = 0;
                    }
                } else {
                    armCandidateStart = 0;  // reset if it dips back down
                }
            }
            
        }
        break;

        // -------------------------------------------------
        case STATE_ARMED: {

            // Send armed heartbeat
            if (now - lastHeartbeat > HEARTBEAT_INTERVAL_MS) {
                lastHeartbeat = now;
                bf_msp_heartbeat_update(true);
            }

            // If CRSF link is live and arm switch goes low → disarm
            if (pwmSignalPresent && armUs < PWM_DISARM_THRESHOLD) {
                if (disarmCandidateStart == 0) disarmCandidateStart = now;
                if (now - disarmCandidateStart >= ARM_DEBOUNCE_MS) {
                    enterState(STATE_PRE_ARM_DELAY);
                    disarmCandidateStart = 0;
                }
            } else {
                disarmCandidateStart = 0;  // reset if it recovers
            }
        }
        break;

        // -------------------------------------------------
        case STATE_ERROR:
            ledUpdateErrorFlash();
            break;
    }
}

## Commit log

2026-03-18 Update README.md
    updated for pan servo
2026-05-11 added failsafe for each channel and got that working
    [CrossfireELRS.cpp, CrossfireELRS.h, PWMDriver.cpp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]
2026-05-23 Update README.md
    updated pin map
2026-06-24 updated for RP2040 and moved LED init before SerialPIO init
2026-07-01 update for M100 GPS running 10Hz
2026-07-01 added flight timer to the OSD
2026-07-01 added ground radar for Home
2026-07-03 updated mirror issue on home arrow
    [GPS.cpp, QLiteArmer.ino, SharedTelemetry.h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]
2026-07-03 Home arrow and ground radar is now working correctly
    [QLiteArmer.ino, SharedTelemetry.h, bf_msp.cpp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]
2026-07-04 updated ground radar radius and configuration
2026-07-04 added reset altitude on arming
    [QLiteArmer.ino, Telemetry.h]
2026-07-08 added box stl files
    [QliteArmer Box end cap.stl, QliteArmer Box.stl]
2026-07-11 updated with delay between LED init and GPS
2026-07-12 added show throttle percent
2026-07-12 updated battery voltage icon indicator
2026-07-12 Polish, and cell voltage
2026-07-18 updated ground radar and defaults for channel range
2026-07-18 Version 1.0 and final update to ground radar
2026-07-18 updated sample image
2026-07-18 updated with PCB link
2026-07-26 added DJI OSD sample image
2026-08-11 fixed issue where it might reset home on Rx flicker
    [config.h, state_machine.cpp]
2026-08-12 fixed default to imperial
    [config.h]
2026-09-26 updated to correctly initialize the pwm driver and ESC
    [CrossfireELRS.cpp, CrossfireELRS.h, PWMDriver.cpp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]
